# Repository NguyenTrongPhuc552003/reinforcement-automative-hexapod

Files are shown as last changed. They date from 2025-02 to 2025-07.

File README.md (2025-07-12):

## NOTE: This hexapod project is still under development and may not be fully functional. So, please wait for an official release is coming soon!

# Hexapod Robot Control System

A comprehensive control system for a six-legged robot (hexapod) using BeagleBone AI (or Black), featuring both kernel-space drivers and user-space applications with reinforcement learning capabilities.

<p align="center">
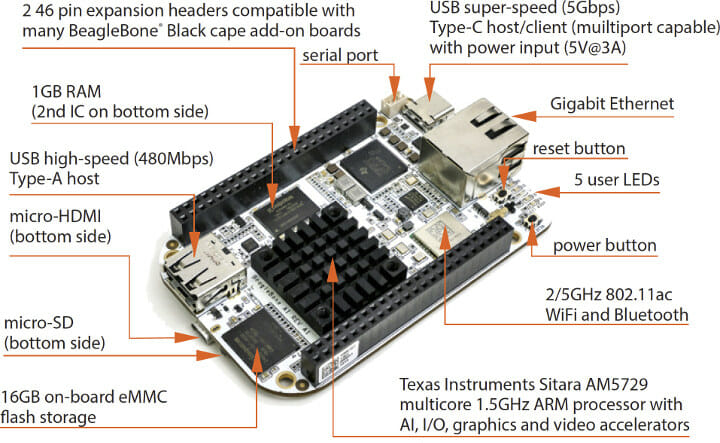
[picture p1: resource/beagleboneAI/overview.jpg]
Hexapod Robot
  
</p>

## Project Overview

This project implements a complete software stack for controlling a 6-legged robot with 18 servo motors (3 per leg), including:

- **Kernel-Space Components**:
  - Linux kernel driver for servo control (PCA9685 PWM controllers)
  - IMU sensor driver (MPU6050) for orientation sensing
  - Hardware abstraction layer for unified device access
  
- **User-Space Components**: 
  - Kinematics library for precise leg positioning
  - Gait generation for various walking patterns
  - Calibration system for mechanical offset compensation
  - Interactive control interface

- **Reinforcement Learning**:
  - TD3 (Twin Delayed Deep Deterministic Policy Gradient) implementation
  - Hardware acceleration via TIDL and OpenCL
  - Simulation-to-real transfer capabilities
  - On-robot inference engine

## System Architecture

The system follows a layered architecture with hardware abstraction. For visual reference, see the architecture diagrams in the `/docs/diagrams/image` directory:

- [Deployment Diagram](docs/diagrams/image/deployment.png): Hardware and software deployment
- [Component Diagram](docs/diagrams/image/component.png): Hardware component interactions
- [Sequence Diagram](docs/diagrams/image/sequence.png): Runtime interactions
- [State Diagram](docs/diagrams/image/state.png): Hardware state transitions
- [Class Diagram](docs/diagrams/image/class.png): Software class structure
- [Building Process](docs/diagrams/image/building.png): Build and deployment process

```t
.
├── driver/          # Linux kernel device drivers
├── app/             # User applications and libraries
├── docs/            # Documentation
└── scripts/         # Build and utility scripts
```

## Features

- Multiple gait patterns (tripod, wave, ripple)
- Real-time IMU feedback
- Inverse kinematics for precise leg control
- Hardware abstraction layer
- Comprehensive test suite
- Interactive debugging tools

## Prerequisites

- BeagleBone AI (or Black) running Linux 4.14+
- I2C enabled (bus 3)
- 18x servo motors (MG996R recommended)
- 1x MPU6050 IMU sensor
- 2x PCA9685 PWM controllers

## Quick Start

1. Build the kernel module:
   ```bash
   ./scripts/build.sh -b driver
   ```

2. Install the kernel module on BeagleBone AI:
   ```bash
   ./install.sh
   ```

3. Build user-space applications:
   ```bash
   ./scripts/build.sh -b app
   ```

4. Run the test utility on BeagleBone AI:
   ```bash
   ./test_servo
   ```

## Development

See individual README files in subdirectories for detailed development guides:
- [Kernel Driver README](driver/README.md)
- [User Space README](app/README.md)
- [Hardware Overview README](hardware/README.md)
- [Cross-compile Environment README](docker/README.md)
- [Documentation](docs/README.md)

## Testing

Individual tests:
```bash
./test_servo       # Test servo control
./test_mpu6050     # Test IMU sensor
./test_movement    # Test movements like tripod, ripple, ...
./test_calibration # Test servos offset for each leg
./test_hcsr04      # Test HC-SR04 sensor
```

## Troubleshooting

### Sensor Issues
- **Zero IMU readings**: The MPU6050 enters sleep mode to save power. The driver now automatically wakes it before readings.
- **Erratic IMU behavior**: Check I2C connections and ensure proper power supply voltage.

### Servo Issues
- **Servos not moving**: Check power supply and ensure driver is properly loaded
- **Erratic movement**: Verify calibration settings and check for loose connections

## Documentation

- [Hardware Setup](docs/hardware.md)
- [Software Architecture](docs/architecture.md)
- [Quick Start Guide](docs/quickstart.md)

## Contributing

1. Fork the repository
2. Create a feature branch
3. Commit your changes
4. Push to the branch
5. Create a Pull Request

## License


This project is licensed under the terms of the GNU General Public License v2.0.

## Authors

- StrongFood - I mean **"TrongPhuc"**

## Acknowledgments

- BeagleBoard.org
- Linux Kernel Community

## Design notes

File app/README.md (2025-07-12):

# Hexapod Robot Control Application

## Overview

This application provides a comprehensive control system for a 6-legged (hexapod) robot. It implements advanced kinematics, gait generation, sensor integration, and balance control to enable smooth and adaptive movement capabilities.

## Features

- **Multiple Gait Patterns**: Tripod, Wave, and Ripple gaits with configurable parameters
- **Adaptive Movement**: Dynamic speed, direction, and height control
- **Sensor Integration**: Support for MPU6050 (6-axis) and ADXL345 (3-axis) IMU sensors
- **Obstacle Detection**: Ultrasonic sensor integration with automatic avoidance
- **Balance Mode**: Self-stabilizing capability using IMU feedback
- **Interactive Control**: Real-time keyboard control interface
- **Diagnostics**: Performance monitoring and hardware verification tools
- **Calibration**: Joint calibration system for mechanical adjustments

## Architecture

The application follows a modular, object-oriented design with several key components:

- **Hexapod**: Hardware abstraction layer for the robot platform
- **Kinematics**: Mathematical model for leg positioning and inverse kinematics
- **Gait**: Movement pattern generation and coordination
- **Controller**: High-level control and command interpretation
- **Calibration**: Servo calibration management
- **Application**: Main program and user interface

## Building the Application

### Prerequisites

- ARM cross-compiler (arm-linux-gnueabihf-g++)
- C++17 compatible compiler
- Standard development libraries

### Compilation

The project uses a Makefile build system with the following targets:

```bash
# Standard build (optimized)
./scripts/build.sh -b app

# Debug build with additional debug information
./scripts/build.sh -b app DEBUG=1

# Run tests for help
./scripts/test.sh -h

# Clean build artifacts
./scripts/build.sh -c app

# Install to target location
./scripts/deploy.sh
```

## Usage

### Controls

| Key | Function |
|---|---|
| W / S | Move forward/backward |
| A / D | Rotate left/right |
| I / K | Raise/lower body |
| J / L | Tilt left/right |
| 1 - 3 | Select gait (1=Tripod, 2=Wave, 3=Ripple) |
| + / - | Increase/decrease speed |
| SPACE | Stop and center legs |
| B | Toggle balance mode |
| \[ / \] | Decrease/increase balance sensitivity |
| U | Toggle ultrasonic sensor |
| T | Toggle telemetry display |
| P | Toggle performance monitoring |
| M | Run servo diagnostics |
| H | Show help |
| Q | Quit |

### Telemetry Display

When enabled, the telemetry shows:
- IMU sensor readings
- Current controller state
- Performance metrics
- Balance mode status

### Balance Mode

The balance mode uses IMU sensor data to automatically adjust the robot's posture in response to tilting or uneven surfaces. This can be fine-tuned using the response factor and deadzone settings.

## Test Programs

The `test/` directory contains individual test programs for specific components:

- **servo.cpp**: Test servo motor control
- **mpu6050.cpp**: Test MPU6050 sensor readings
- **adxl345.cpp**: Test ADXL345 accelerometer readings
- **movement.cpp**: Test movement patterns
- **hcsr04.cpp**: Test ultrasonic distance sensor
- **calibration.cpp**: Test calibration procedures
- **balance.cpp**: Test balance mode functionality

## Safety Features

- Automatic obstacle detection and avoidance
- Graceful signal handling for clean shutdown
- Leg centering on startup and shutdown
- Configurable movement speed limits

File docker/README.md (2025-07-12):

# Docker Environment for Hexapod Robot

This directory contains Docker configuration for building and running the hexapod robot software in isolated containers. The Docker setup provides a consistent development and deployment environment across different systems.

## Available Containers

### 1. Driver Container (`driver.Dockerfile`)

The driver container provides the low-level hardware interface for the hexapod robot:

- PCA9685 servo driver interface
- IMU sensors (MPU6050, ADXL345)
- GPIO control for ultrasonic sensors
- I2C bus management

### 2. Application Container (`app.Dockerfile`)

The application container runs the high-level control software:

- Kinematics and movement algorithms
- Reinforcement learning models (TD3)
- Gait generation and control
- User interface and command processing

### 3. Python TD3 Container (`pytd3.Dockerfile`)

The Python TD3 container runs the TD3 reinforcement learning algorithm:

- TD3 algorithm implementation
- Training and evaluation scripts
- Integration with the application container

## Building the Containers

### Using Docker Compose (Recommended)

The easiest way to build all available containers is using Docker Compose:

```bash
# From the project root directory
./scripts/build.sh -i
```

### Building Individual Containers

To build containers individually:

```bash
# Build the driver container
./scripts/build.sh -i driver

# Build the application container
./scripts/build.sh -i app

# Build the Python TD3 container
./scripts/build.sh -i pytd3
```

## Running the Containers

### Using Docker Compose (Recommended)

```bash
# Start all containers
docker-compose up

# Run in detached mode
docker-compose up -d

# Stop the containers
docker-compose down
```

### Running Individual Containers

```bash
# Run the driver container with hardware access
docker run --privileged --device=/dev/i2c-1 -v /dev:/dev \
  --name hexapod-driver hexapod-driver

# Run the application container
docker run --network=host --name hexapod-app hexapod-app
```

## Configuration

### Environment Variables

You can configure the containers using environment variables:

- `HEXAPOD_LOG_LEVEL`: Set logging level (DEBUG, INFO, WARNING, ERROR)
- `HEXAPOD_HARDWARE_ENABLED`: Enable/disable hardware interface (true/false)
- `HEXAPOD_SENSOR_TYPE`: Set the sensor type (AUTO, MPU6050, ADXL345)

Example using Docker Compose:

```yaml
services:
  app:
    environment:
      - HEXAPOD_LOG_LEVEL=DEBUG
      - HEXAPOD_SENSOR_TYPE=MPU6050
```

### Volume Mounts

The Docker Compose configuration includes several useful volume mounts:

- `/dev`: Provides access to hardware devices
- `/var/log/hexapod`: Stores log files
- `/data/models`: Persists trained models

## Development Workflow

For development, you can mount your source code as volumes:

```bash
docker run -v $(pwd)/app:/app -v $(pwd)/driver:/driver \
  --privileged --device=/dev/i2c-1 \
  hexapod-driver
```

## Troubleshooting

### Hardware Access Issues

If the container can't access hardware devices:

1. Make sure you're using the `--privileged` flag
2. Verify that device paths are correctly mounted
3. Check that the user in the container has permission to access the devices

### Container Communication Issues

If containers can't communicate:

1. Check that they're on the same network
2. Verify that required ports are exposed
3. Ensure service names resolve correctly in Docker Compose

## Security Considerations

The containers use the `--privileged` flag to access hardware, which grants extensive permissions. For production deployments, consider using more restrictive permissions with specific device mappings.

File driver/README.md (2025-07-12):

# Hexapod Robot Driver

## Overview

This directory contains the kernel-level driver for the hexapod robot platform. The driver provides a hardware abstraction layer that interfaces with the servo controllers, IMU sensors, and other hardware components, exposing them through a unified device interface to user applications.

## Features

- **Servo Motor Control**: Precise control of 18 servo motors through the PCA9685 PWM controller
- **Dual IMU Support**:
  - MPU6050 (6-axis: accelerometer + gyroscope)
  - ADXL345 (3-axis accelerometer)
  - Auto-detection capability
- **Joint Calibration**: Hardware-level servo calibration to compensate for mechanical variations
- **Safe Mode Operation**: Automatic protection against invalid positions and commands

## Hardware Components

The driver interfaces with the following hardware components:

| Component | Description | Interface | Address (configurable) |
|---|---|---|---|
| PCA9685_1 | 16-channel PWM controller | I2C | 0x40 |
| PCA9685_2 | 16-channel PWM controller | I2C | 0x41 |
| MPU6050 | 6-axis IMU sensor | I2C | 0x68 |
| ADXL345 | 3-axis accelerometer | I2C | 0x53 |

## Directory Structure

```t
driver/
├── inc/
│   ├── mpu6050.h          # MPU6050 IMU sensor data structures
│   └── pca9685.h          # PCA9685 PWM controller data structures
│   └── adxl345.h          # ADXL345 accelerometer data structures
│   └── servo.h            # Servo motor data structures
├── src/
│   ├── mpu6050.c          # MPU6050 IMU sensor handling code
│   ├── pca9685.c          # PCA9685 PWM controller handling code
│   ├── adxl345.c          # ADXL345 accelerometer handling code
│   └── servo.c            # Servo motor handling code
│   └── main.c             # Main application code
├── Makefile               # System build instructions
└── README.md              # This file
```

## Building and Installation

### Prerequisites

- Linux kernel headers
- Cross-compilation toolchain
- BeagleBone AI device tree (unused yet)

### Build Commands

```bash
./scripts/build.sh -b driver
```

### Installation Steps

1. Copy module:
   ```bash
   ./scripts/deploy.sh
   ```

2. Load module:
   ```bash
   ./scripts/deploy.sh -i
   ```

3. Verify:
   ```bash
   dmesg | grep hexapod
   ls -l /dev/hexapod
   ```

## Driver Interface

### IOCTL Commands

- `SET_LEG_POSITION`: Set servo angles for a specific leg
- `GET_IMU_DATA`: Read IMU data (accelerometer and gyroscope)
- `CALIBRATE`: Set servo calibration offsets
- `CENTER_ALL`: Center all servos to neutral position

### Data Structures

- `hexapod_leg_joint`: Contains hip, knee, ankle angles
- `hexapod_leg_cmd`: Contains leg number and joint angles
- `hexapod_calibration`: Contains leg number and joint offsets
- `hexapod_imu_data`: Contains accelerometer and gyroscope data

### Device Node

- Path: `/dev/hexapod`
- Permissions: 666
- Mode: Character device

## Debugging

Enable debug messages:

```bash
echo 1 > /sys/module/hexapod_driver/parameters/debug
```

## Development

### Adding Features

1. Define IOCTL command in `src/main.c`
2. Implement handler in `src/main.c`
3. Add to user documentation

### Testing

```bash
# Load with debug
./install.sh debug=1

# Monitor messages
dmesg -w
```

### Error Handling

- I2C communication errors
- Invalid parameters
- Resource cleanup
- User input validation

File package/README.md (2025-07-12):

# Hexapod Robot Control System

A comprehensive control system for hexapod robots featuring kernel-level hardware drivers, user space applications, and reinforcement learning capabilities.

## Package Contents

This installation package includes:

### Kernel Driver (`/lib/modules/*/extra/`)
- **hexapod_driver.ko**: Low-level hardware interface kernel module
- Provides device file interface at `/dev/hexapod`
- Supports PCA9685 PWM controller and IMU sensors

### Applications (`/usr/local/bin/`)  
- **hexapod_app**: Main interactive control application
- **test_***: Hardware testing and diagnostic utilities
- Complete keyboard-controlled interface for robot operation

### Utilities (`/opt/hexapod/`)
- **install.sh**: Kernel module management
- **monitor.sh**: System monitoring and diagnostics
- Configuration and calibration tools

## Quick Start

1. **Verify Installation**
   ```bash
   lsmod | grep hexapod_driver
   ls -l /dev/hexapod
   ```

2. **Run Main Application**
   ```bash
   ./hexapod_app
   ```

3. **Test Hardware Components**
   ```bash
   ./test_mpu6050    # Test IMU sensor
   ./test_servo      # Test servo motors
   ./test_balance    # Test balance system
   ```

## Hardware Requirements

- BeagleBone AI or compatible ARM platform
- PCA9685 16-channel PWM driver
- MPU6050 or ADXL345 IMU sensor
- 18 servo motors (3 per leg × 6 legs)
- HC-SR04 ultrasonic sensor (optional)

## System Requirements

- Linux kernel 4.14+ with I2C support
- ARM architecture (armhf/arm64)
- Root access for hardware control
- I2C interface enabled in device tree

## Documentation

Detailed documentation available in:
- `/usr/local/bin/README.md` - Application usage
- `/opt/hexapod/README.md` - Utility scripts  
- `/lib/modules/*/extra/README.md` - Kernel module

## Troubleshooting

**Module Loading Issues:**
```bash
sudo dmesg | grep hexapod
sudo modprobe hexapod_driver
```

**Permission Errors:**
```bash
sudo chmod 666 /dev/hexapod
sudo usermod -a -G dialout $USER
```

**Hardware Detection:**
```bash
i2cdetect -y -r 3
./monitor.sh -h   # Call for help more options
```

## Updates and Support

- Project repository: https://github.com/NguyenTrongPhuc552003/reinforcement-automative-hexapod.git
- Issue tracker: https://github.com/NguyenTrongPhuc552003/reinforcement-automative-hexapod/issues
- Documentation: https://github.com/NguyenTrongPhuc552003/reinforcement-automative-hexapod/tree/main/docs

## Version Information

Check installed version:
```bash
dpkg -l | grep hexapod
modinfo hexapod_driver | grep version
```

---
© 2025 StrongFood. Licensed under GPL v2.0

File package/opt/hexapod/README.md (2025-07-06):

# Hexapod Utilities

This directory contains utility scripts for the Hexapod Robot Control System.

## Available Scripts

### install.sh
Kernel module management utility
```bash
# Install/load kernel module
sudo ./install.sh

# Remove/unload kernel module  
sudo ./install.sh -r

# Show status
./install.sh -s
```

### monitor.sh  
System monitoring and diagnostic tool
```bash
# Monitor system activities
./monitor.sh

# Monitor with logging
./monitor.sh -l

# Continuous monitoring
./monitor.sh -c
```

## Additional Utilities
If PyTD3 reinforcement learning module is installed:
- **pytd3/**: Python reinforcement learning components
- **config/**: Configuration files and calibration data

## System Integration
These utilities are designed to work with:
- BeagleBone AI hardware platform
- Debian-based Linux distributions  
- I2C hardware interface
- GPIO control systems

## Maintenance
Regular maintenance tasks:
```bash
# Check system health
sudo ./monitor.sh -h

# Backup calibration data
cp /etc/hexapod/calibration.cfg ~/hexapod_backup.cfg

# Update kernel module
sudo ./install.sh -r && sudo ./install.sh
```

## Support
For technical support:
- Check system logs: `journalctl -u hexapod`
- Review hardware connections
- Verify I2C functionality: `i2cdetect -r 1`

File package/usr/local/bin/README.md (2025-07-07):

# Hexapod Executables

This directory contains the main applications and test programs for the Hexapod Robot Control System.

## Main Application
- **hexapod_app**: Main hexapod control application with keyboard interface

## Test Programs
- **test_mpu6050**: Test MPU6050 6-axis IMU sensor functionality
- **test_adxl345**: Test ADXL345 3-axis accelerometer  
- **test_servo**: Test individual servo motor control
- **test_movement**: Test basic movement patterns and gaits
- **test_balance**: Test balance control system with IMU feedback
- **test_calibration**: Interactive servo calibration utility
- **test_hcsr04**: Test HC-SR04 ultrasonic distance sensor

## Usage
All programs require root privileges to access hardware:

```bash
# Run main application
sudo hexapod_app

# Test specific hardware
sudo test_mpu6050
sudo test_servo
sudo test_balance

# Interactive calibration
sudo test_calibration
```

## Main Application Controls
- **WASD**: Movement (forward/back/rotate)
- **IJKL**: Height and tilt control  
- **123**: Gait selection (tripod/wave/ripple)
- **+/-**: Speed adjustment
- **Space**: Stop and center
- **Q**: Quit

## Prerequisites
- Kernel module must be loaded (hexapod_driver)
- Hardware must be properly connected
- I2C interface must be enabled

## Troubleshooting
- Check kernel module: `lsmod | grep hexapod_driver`
- Verify device file: `ls -l /dev/hexapod`
- Monitor system logs: `dmesg | tail`

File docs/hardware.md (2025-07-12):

# Hexapod Hardware Documentation

## Overview

This document describes the hardware components of the hexapod robot and provides detailed specifications, wiring diagrams, and configuration information.

Hexapod Hardware Overview

For detailed visual representation of hardware organization, see the [Component Diagram](diagrams/image/component.png) and [Deployment Diagram](diagrams/image/deployment.png).

## Robot Specifications

| Parameter | Value |
|---|---|
| Dimensions | 300mm × 300mm × 150mm (L×W×H) |
| Weight | ~1.5kg (without battery) |
| Operating Voltage | 6V (servos), 5V (logic) |
| Power Consumption | 2-10A depending on movement |
| Maximum Speed | ~0.3m/s |
| Control Board | BeagleBone AI/Black |
| Servo Motors | 18× MG996R (or compatible) |
| Degrees of Freedom | 18 (3 per leg) |
| Operating Time | ~1 hour (with 2800mAh battery) |
| Sensing | 6-axis IMU (accelerometer + gyroscope) |

## Component List

| Component Description | Quantity | Notes |
|---|---|---|
| BeagleBone AI/Black | 1 | Main control board |
| MG996R Servo Motors | 18 | 3 per leg (hip, knee, ankle) |
| PCA9685 PWM Controller | 2 | 16-channel PWM controller |
| MPU6050 IMU Sensor | 1 | 6-axis accelerometer + gyroscope |
| 6V 10A Power Supply | 1 | For powering servos |
| Voltage Regulator 5V | 1 | For logic power |
| Aluminum/Plastic Brackets | 18 | For leg joints |
| Body Frame | 1 | Central chassis |
| Leg Segments | 18 | Connecting rods for legs |
| Foot Pads | 6 | Non-slip contact points |
| Wires and Connectors | Assorted | For electrical connections |
| Mounting Hardware | Assorted | Screws, nuts, standoffs |

## Mechanical Architecture

The hexapod follows a standard hexapod design with 6 legs arranged radially around a central body:

- **Body**: Hexagonal or circular platform housing the control electronics
- **Legs**: 6 legs with 3 joints each (hip, knee, ankle)
- **Joint Arrangement**:
  - Hip: Rotates horizontally (parallel to body)
  - Knee: Rotates vertically (perpendicular to hip)
  - Ankle: Rotates vertically (perpendicular to knee)

### Dimensions

- **Body Diameter**: 150mm
- **Leg Segments**:
  - Hip to Knee (COXA): 30mm
  - Knee to Ankle (FEMUR): 85mm
  - Ankle to Foot (TIBIA): 130mm
- **Total Leg Extension**: ~245mm fully extended

## Electrical Architecture

### Power System

- **Main Power**: 6V, 10A power supply or battery
- **Power Distribution**:
  - Separate power rails for servos and logic
  - Common ground between all components
- **Protection**:
  - Fuse on main power line (10A)
  - Reverse polarity protection
  - Logic level isolation between BeagleBone and servo power

### Control System

- **Main Controller**: BeagleBone AI/Black
  - AM5729 processor
  - 1GB DDR3 RAM
  - 16GB onboard eMMC
  - Linux operating system

- **Servo Control**: Via PCA9685 PWM controllers
  - 2× PCA9685 boards (primary and secondary)
  - I2C communication from BeagleBone
  - 50Hz PWM signal generation

- **Sensing**:
  - MPU6050 IMU for orientation detection
  - Additional sensor connections available for expansion

## I2C Bus Configuration

The I2C bus 2 on BeagleBone is used for connecting sensors and actuators:

| Device Description | I2C Address | Bus | Description |
|--- |---|-----|---|
| MPU6050 | 0x68 | 3 | 6-axis IMU sensor |
| PCA9685 Primary | 0x40 | 3 | 16-channel PWM controller |
| PCA9685 Secondary  | 0x71 | 3 | 16-channel PWM controller |

### BeagleBone Pin Configuration

| BeagleBone Pin | Function | Connected To |
|---|---|---|
| P9_19 | I2C2_SCL | SCL of all I2C devices |
| P9_20 | I2C2_SDA | SDA of all I2C devices |
| P9_1, P9_2 | GND | Ground for all devices |
| P9_7, P9_8 | SYS_5V | Logic power for shields |
| P9_3, P9_4 | DC_3.3V | 3.3V sensors (e.g. MPU6050) |

## Servo Motor Specifications

Type: MG996R (or compatible) high-torque metal gear servo

| Parameter | Specification |
|---|---|
| Operating Voltage  | 4.8V to 6.6V |
| Stall Torque | 9.4 kg·cm (4.8V) / 11 kg·cm (6.0V) |
| Speed | 0.17 sec/60° (4.8V) / 0.14 sec/60° (6.0V) |
| Weight | 55g |
| Dimensions | 40.7 × 19.7 × 42.9 mm |
| Control Signal | PWM, 1-2ms pulse, 50Hz |
| Rotation Range | 180° (controlled as ±90°) |
| Working Temperature| -30°C to +60°C |

## Servo Mapping

Each servo is connected to a specific channel on the PCA9685 controllers.

| Leg | Joint | PWM Channel  | Controller |
|-----|---|---|---|
| 0 | Hip | 0 | Primary |
| | Knee  | 1 | Primary |
|_____| Ankle | 2 | Primary |
| 1 | Hip | 4 | Primary |
| | Knee  | 5 | Primary |
|_____| Ankle | 6 | Primary |
| 2 | Hip | 8 | Primary |
| | Knee  | 9 | Primary |
|_____| Ankle | 10 | Primary |
| 3 | Hip | 0 | Secondary  |
| | Knee  | 1 | Secondary  |
|_____| Ankle | 2 | Secondary  |
| 4 | Hip | 4 | Secondary  |
| | Knee  | 5 | Secondary  |
|_____| Ankle | 6 | Secondary  |
| 5 | Hip | 8 | Secondary  |
| | Knee  | 9 | Secondary  |
|_____| Ankle | 10 | Secondary  |

## MPU6050 IMU Configuration

The MPU6050 provides orientation data for the hexapod:

| Parameter | Configuration |
|---|---|
| I2C Address | 0x68 |
| Accelerometer Range | ±2g |
| Gyroscope Range | ±500 degrees/second |
| Sample Rate | 100Hz |
| Low-Pass Filter | 10Hz |
| Orientation | X forward, Y right, Z up |

### Power Management

The MPU6050 has built-in power management features that may put it into sleep mode after periods of inactivity. The driver automatically handles waking the device when readings are requested, ensuring consistent sensor data even after extended periods between readings.

Key power management features:
- Sleep mode: Automatically entered to conserve power
- Wake-on-read: Driver automatically detects and wakes the device when readings are requested
- Clock source: PLL with X-axis gyroscope reference for stability

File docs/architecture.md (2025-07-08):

# Hexapod Robot System Architecture

This document describes the architecture of the reinforcement learning-enabled hexapod robot system, detailing the major components, their interactions, and the key design patterns used.

## System Overview

The hexapod robot system is a multi-layered architecture that combines hardware control, kinematics, gait generation, and high-level control with reinforcement learning capabilities. The system is designed to be modular, extensible, and robust to environmental changes.

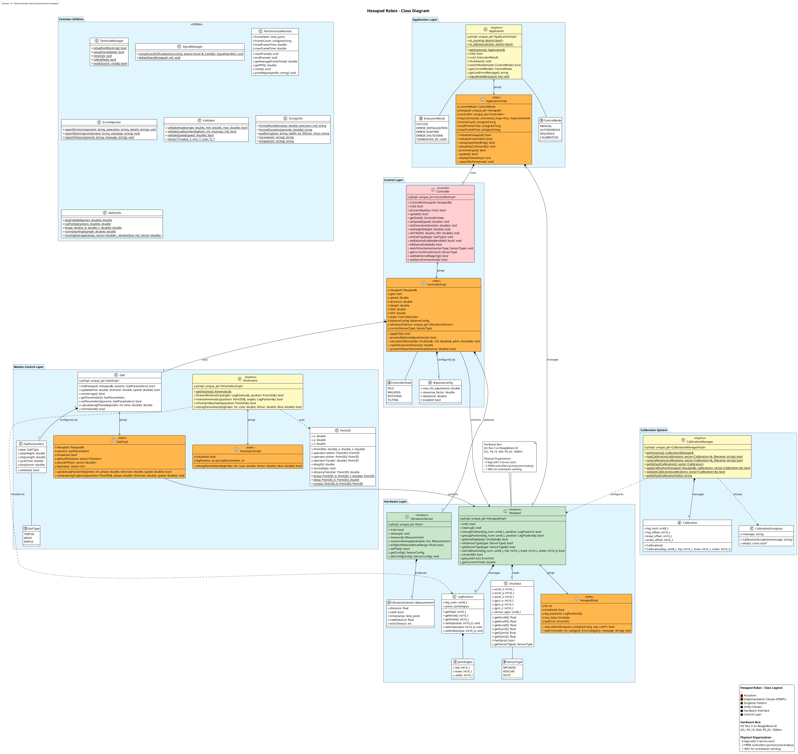
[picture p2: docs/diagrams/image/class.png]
Architecture Overview


## Architectural Layers

The system is organized into the following layers, from lowest to highest level:

### 1. Hardware Layer

The hardware layer provides direct interaction with the physical components of the robot:

- **Kernel Driver**: Low-level kernel module for hardware access
- **Hardware Abstraction**: C++ interface to the kernel driver
- **Sensor Integration**: IMU and ultrasonic sensor management

#### Key Components:
- `hexapod::Hexapod`: Hardware abstraction layer for servo control
- `PCA9685` driver: PWM controller for servo motors
- `MPU6050` and `ADXL345` drivers: IMU sensor interfaces
- `UltrasonicSensor`: HC-SR04 distance sensor interface

### 2. Kinematics Layer

The kinematics layer handles the mathematical models for leg positioning:

- **Forward Kinematics**: Calculate leg positions from joint angles
- **Inverse Kinematics**: Calculate joint angles from desired positions
- **3D Geometry**: Vector operations and transformations

#### Key Components:
- `kinematics::Kinematics`: Singleton class providing forward and inverse kinematics
- `kinematics::Point3D`: 3D vector class with mathematical operations

### 3. Gait Layer

The gait layer manages leg movement patterns and coordination:

- **Gait Patterns**: Tripod, wave, and ripple gaits
- **Trajectory Generation**: Calculate foot paths for smooth movement
- **Gait Parameters**: Configurable stepping height, length, and timing

#### Key Components:
- `gait::Gait`: Gait pattern generator
- `gait::GaitParameters`: Configuration for different gait types

### 4. Control Layer

The control layer provides high-level robot control:

- **Movement Control**: Direction and speed management
- **Balance System**: Active balance using IMU feedback
- **Obstacle Avoidance**: Distance-based movement adjustment

#### Key Components:
- `controller::Controller`: High-level robot controller
- `controller::BalanceConfig`: Balance system parameters

### 5. Application Layer

The application layer handles user interaction and system coordination:

- **User Interface**: Keyboard input and telemetry display
- **System Management**: Initialization, shutdown, and error handling
- **Performance Monitoring**: Timing and metrics tracking

#### Key Components:
- `application::Application`: Main application singleton
- `common::TerminalManager`: Terminal input handling
- `common::SignalManager`: Signal handling for graceful shutdown
- `calibration::CalibrationManager`: Servo calibration management

### 6. Reinforcement Learning Layer

The reinforcement learning layer provides adaptive behavior:

- **TD3 Algorithm**: Twin Delayed Deep Deterministic Policy Gradient
- **State Representation**: Robot state encoding
- **Action Mapping**: Transform RL outputs to robot commands

#### Key Components:
- `pytd3` module: Python implementation of TD3 algorithm
- `td3bridge`: C++/Python communication interface

## Communication and Data Flow

### Internal Communication

Components communicate through well-defined interfaces:

1. **Hardware to Kinematics**: The kinematics layer translates between joint angles and 3D positions
2. **Kinematics to Gait**: The gait layer uses kinematics to generate coordinated leg movements
3. **Gait to Controller**: The controller uses the gait generator to produce walking patterns
4. **Controller to Application**: The application orchestrates the controller based on user input

### External Communication

The system communicates with external components through:

- **Kernel Interface**: IOCTL calls for hardware communication
- **Python Bridge**: ZeroMQ-based interface for reinforcement learning integration
- **Telemetry Output**: Real-time system status display

## Key Design Patterns

### 1. PIMPL (Pointer to Implementation)

The system extensively uses the PIMPL idiom to:
- Hide implementation details
- Maintain ABI stability
- Reduce compilation dependencies

Example implementation:
```cpp
// Header file
class Controller {
public:
    Controller(hexapod::Hexapod &hexapod);
    ~Controller();
    bool init();
    // Public API methods
private:
    std::unique_ptr<ControllerImpl> pImpl;
};

// Implementation file
class ControllerImpl {
public:
    ControllerImpl(hexapod::Hexapod &hexapod) : hexapod(hexapod) {}
    // Implementation details
    hexapod::Hexapod &hexapod;
};

Controller::Controller(hexapod::Hexapod &hexapod)
    : pImpl(std::make_unique<ControllerImpl>(hexapod)) {}
```

### 2. Singleton Pattern

Singletons are used for system-wide resources:
- `Application`: Main application controller
- `Kinematics`: Shared kinematics calculations
- `CalibrationManager`: Centralized calibration management

Example implementation:
```cpp
class Kinematics {
public:
    static Kinematics& getInstance() {
        static Kinematics instance;
        return instance;
    }
    
    // Delete copy and move operations
    Kinematics(const Kinematics&) = delete;
    Kinematics& operator=(const Kinematics&) = delete;
    Kinematics(Kinematics&&) = delete;
    Kinematics& operator=(Kinematics&&) = delete;

private:
    Kinematics() {}
};
```

### 3. Strategy Pattern

The system uses the strategy pattern for different gait types and control modes:
- Different gaits (tripod, wave, ripple) share a common interface
- Control modes (manual, autonomous) can be switched at runtime

### 4. Observer Pattern

The system implements observer patterns for monitoring:
- Signal handlers observe system signals
- Performance monitors observe system metrics

### 5. Factory Pattern

Factory patterns are used for creating specialized objects:
- Gait pattern creation
- Calibration data initialization

## Error Handling Strategy

The system implements a comprehensive error handling approach:

1. **Error Classification**: Errors are categorized by type (hardware, communication, etc.)
2. **Error Propagation**: Errors propagate upward with additional context
3. **Retry Logic**: Critical operations have built-in retry mechanisms
4. **Graceful Degradation**: The system continues operating with reduced functionality when possible

Example error handling:
```cpp
bool Hexapod::setLegPosition(uint8_t leg_num, const LegPosition &position)
{
    if (!pImpl->initialized) {
        pImpl->setError(ErrorInfo::ErrorCode::NOT_INITIALIZED, ErrorCategory::PARAMETER,
                       "Hexapod not initialized");
        return false;
    }
    
    // Implement retry logic for hardware operations
    for (int retry = 0; retry < MAX_RETRIES; retry++) {
        if (sendPositionCommand(leg_num, position))
            return true;
            
        if (retry < MAX_RETRIES - 1)
            usleep(RETRY_DELAY_US);
    }
    
    pImpl->setError(ErrorInfo::ErrorCode::COMM_ERROR, ErrorCategory::COMMUNICATION,
                   "Failed to set leg position after retries");
    return false;
}
```

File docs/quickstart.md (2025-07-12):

# Hexapod Robot - Quick Start Guide

This guide will help you quickly set up and operate the reinforcement learning-enabled hexapod robot.

## Prerequisites

- BeagleBone Black or compatible single-board computer
- Properly assembled hexapod with 18 servos (3 per leg)
- IMU sensor (MPU6050 or ADXL345)
- Optional: Ultrasonic distance sensor
- Power supply (7.4V-12V recommended)

## Installation

### Option 1: Using Pre-built Image

1. Download the pre-built image from our repository
2. Flash the image to a microSD card
3. Insert the card into your BeagleBone and power on
4. The system will boot automatically

### Option 2: Manual Installation

1. Install dependencies:
   ```bash
   sudo apt update
   sudo apt install -y build-essential cmake git docker
   ```

2. Clone the repository:
   ```bash
   git clone https://github.com/NguyenTrongPhuc552003/reinforcement-automative-hexapod.git
   cd reinforcement-automative-hexapod
   ```

3. Build the project:
   ```bash
   ./scripts/build.sh
   ```

4. Deploy the applications to your BeagleBone:
   ```bash
   ./scripts/deploy.sh
   ```

## Hardware Setup

1. Connect the servo controller (PCA9685) to I2C bus
2. Connect the IMU sensor (MPU6050 or ADXL345) to I2C bus
3. Connect ultrasonic sensor (optional) to designated GPIO pins
4. Connect power supply to the servo power rail

## Running the Hexapod

1. Install the hexapod driver:
   ```bash
   ./install.sh
   ```

2. Launch the hexapod application:
   ```bash
   ./hexapod_app
   ```

3. Test the hexapod's movement:
   ```bash
   ./test_movement
   ```

## Basic Controls

Once the application is running, use the following keyboard controls:

| Key | Function |
|---|---|
| W | Walk forward |
| S | Walk backward |
| A | Rotate left |
| D | Rotate right |
| I / K | Raise/lower body |
| J / L | Tilt left/right |
| 1 / 2 / 3 | Switch gait (Tripod/Wave/Ripple) |
| +/- | Increase/decrease speed |
| Space | Stop and center legs |
| B | Toggle balance mode |
| \[ / \] | Adjust balance sensitivity |
| U | Toggle ultrasonic sensor |
| T | Toggle telemetry display |
| P | Toggle performance monitoring |
| H | Display help |
| Q | Quit application |

## Advanced Features

### Balance Mode

Enable automatic balancing with the 'B' key. The hexapod will use IMU data to maintain stability:
- Use '\[' and '\]' to adjust sensitivity
- Balance works in all movement modes

### Sensor Options

The system supports multiple sensor configurations:
- MPU6050: 6-axis IMU with accelerometer and gyroscope
- ADXL345: 3-axis accelerometer
- Switch between them with 'X' and 'C' keys

### Obstacle Avoidance

When ultrasonic sensor is enabled ('U' key):
- Automatically slows down when approaching obstacles
- Stops and backs away from close obstacles

## Troubleshooting

### Common Issues

1. **Servo jittering**
   - Check power supply voltage
   - Verify calibration values
   - Ensure I2C connection is stable

2. **Unresponsive controls**
   - Check if terminal is in the correct mode
   - Verify driver is loaded (`lsmod | grep hexapod`)
   - Restart the application

3. **IMU errors**
   - Verify I2C connections
   - Try switching sensor type (MPU6050/ADXL345)
   - Run diagnostics with 'P' command

### Running Diagnostics

Use the 'M' key to run comprehensive diagnostics on:
- Servo mapping
- Controller connectivity
- Sensor readings

## Next Steps

After getting familiar with basic operation:

1. Explore the reinforcement learning module in `pytd3/`
2. Customize gait patterns in the `gait.cpp` file in `app/src/`
3. Create your own sequences and behaviors
4. See the full documentation for advanced API usage

## Support

For additional help, please:
- Check the complete documentation in the `docs/` directory
- File issues on our GitHub repository
- Join our community Discord server for real-time assistance

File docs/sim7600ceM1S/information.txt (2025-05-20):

•	Supply voltage range on VCC PIN: 4.8V ~ 16V
•	Control Via AT Commands
•	Operation temperature: -40℃ to +85℃
•	Dimensions: 30.0*30.0*2.9mm
•	Weight: : 5.7 ± 0.2g
•	GNSS:GPS/GLONASS/BeiDou/Galileo
•	Frequency:
•	LTE-FDD B1/B3/B5/B8
•	UMTS/HSDPA/HSPA+ B1/B8
•	GSM/GPRS/EDGE 900/1800MHz

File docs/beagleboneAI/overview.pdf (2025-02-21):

# BeagleBone AI

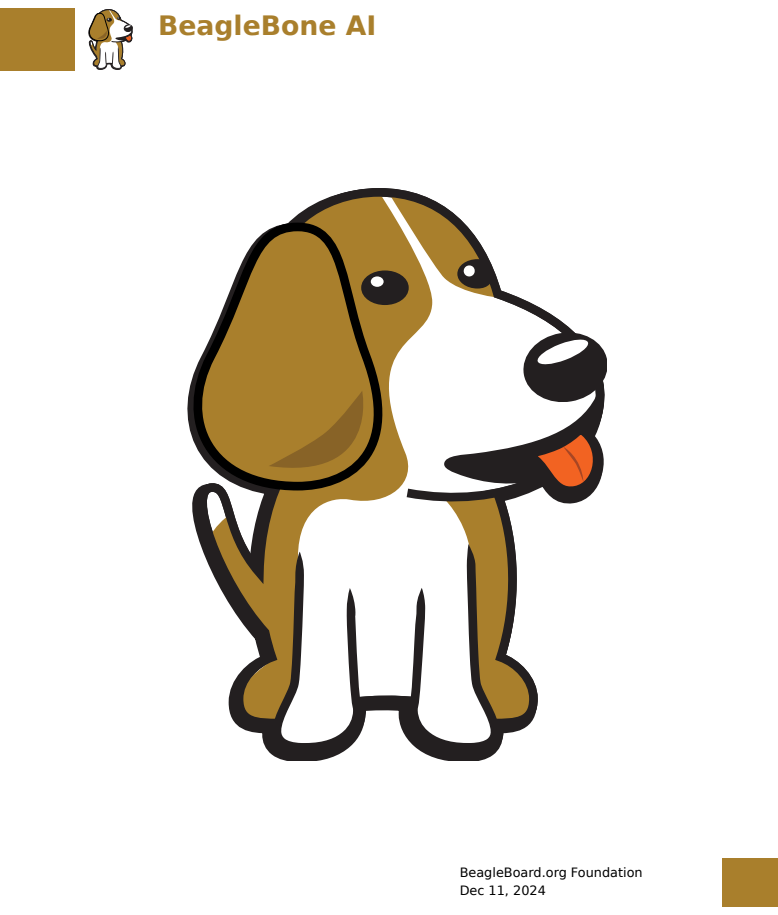
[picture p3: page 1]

BeagleBoard.org Foundation
Dec 11, 2024

# Table of contents

1 Introduction | 3
2 Quick start | 7
3 Design and specifications | 17

i

4 Expansion | 39
5 Cape Board Support | 57
6 Demos & Tutorials | 61
7 Additional Support Information | 69

ii

BeagleBone AI

BeagleBone AI is based on the Texas Instruments AM5729 (https://www.ti.com/product/AM5729) dual-core Cortex-A15 SoC with flexible BeagleBone Black header and mechanical compatibility. BeagleBone AI makes it easy to explore how artificial intelligence (AI) can be used in everyday life via the TI C66x digital-signal-processor (DSP) cores and embedded-vision-engine (EVE) cores supported through an optimized TIDL machine learning OpenCL API with pre-installed tools. Focused on everyday automation in industrial, commercial and home applications.

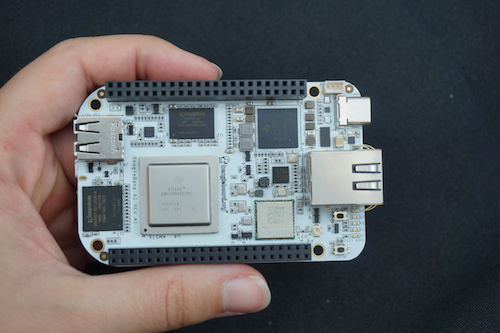
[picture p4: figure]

Table of contents | 1

### 2 Table of contents

# Chapter 1

# Introduction

Built on the proven BeagleBoard.org® open source Linux approach, BeagleBone® AI fills the gap between small SBCs and more powerful industrial computers. Based on the Texas Instruments AM5729, developers have access to the powerful SoC with the ease of BeagleBone® Black header and mechanical compatibility. BeagleBone® AI makes it easy to explore how artificial intelligence (AI) can be used in everyday life via TI C66x digital-signal-processor (DSP) cores and embedded-vision-engine (EVE) cores supported through an optimized TIDL machine learning OpenCL API with pre-installed tools. Focused on everyday automation in industrial, commercial and home applications.

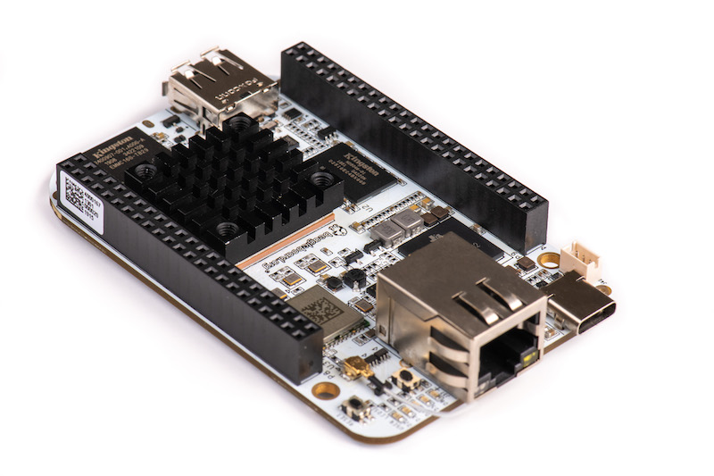
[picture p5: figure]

3

## 1.1 BeagleBone AI Overview

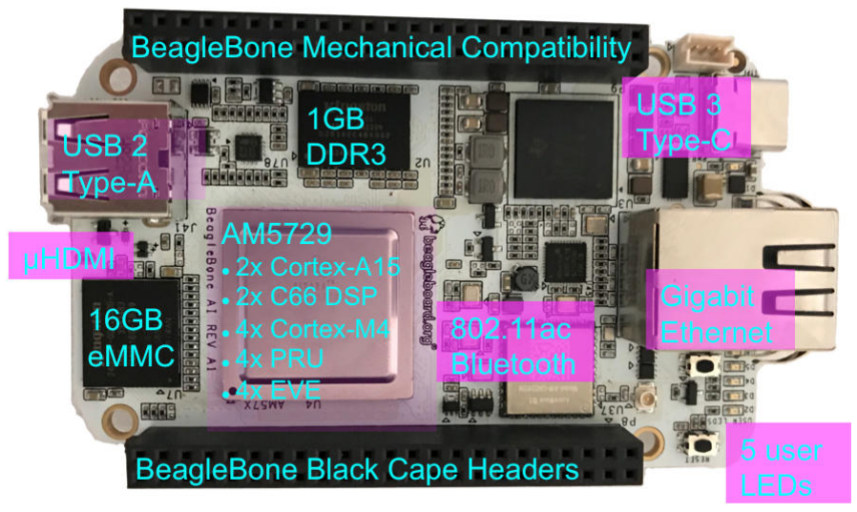
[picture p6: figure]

### 1.1.1 BeagleBone® AI Features

## 1.2 Main Processor Features of the AM5729 Within BeagleBone® AI

- Dual 1.5GHz ARM® Cortex®-A15 with out-of-order speculative issue 3-way superscalar execution pipeline for the fastest execution of existing 32-bit code
- 2 C66x Floating-Point VLIW DSP supported by OpenCL
- 4 Embedded Vision Engines (EVEs) supported by TIDL machine learning library
- 2x Dual-Core Programmable Real-Time Unit (PRU) subsystems (4 PRUs total) for ultra low-latency control and software generated peripherals
- 2x Dual ARM® Cortex®-M4 co-processors for real-time control
- IVA-HD subsystem with support for 4K @ 15fps H.264 encode/decode and other codecs @ 1080p60
- Vivante® GC320 2D graphics accelerator
- Dual-Core PowerVR® SGX544™ 3D GPU

## 1.3 Communications

- BeagleBone Black header and mechanical compatibility
- 16-bit LCD interfaces
- 4+ UARTs
- 2 I2C ports
- 2 SPI ports

### 4 Chapter 1. Introduction

- Lots of PRU I/O pins

## 1.4 Memory

- 1GB DDR3L
- 16GB on-board eMMC flash

## 1.5 Connectors

- USB Type-C connector for power and SuperSpeed dual-role controller
- Gigabit Ethernet
- 802.11ac 2.4/5GHz WiFi via the AzureWave AW-CM256SM

## 1.6 Out of Box Software

- Zero-download out of box software environment

### 1.6.1 Board Component Locations

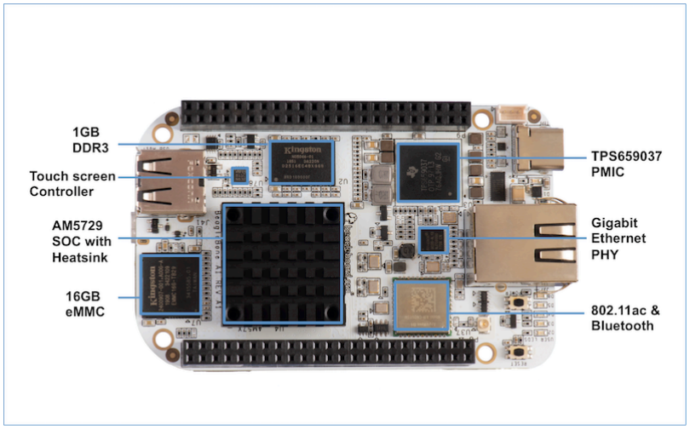
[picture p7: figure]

1.4. Memory | 5

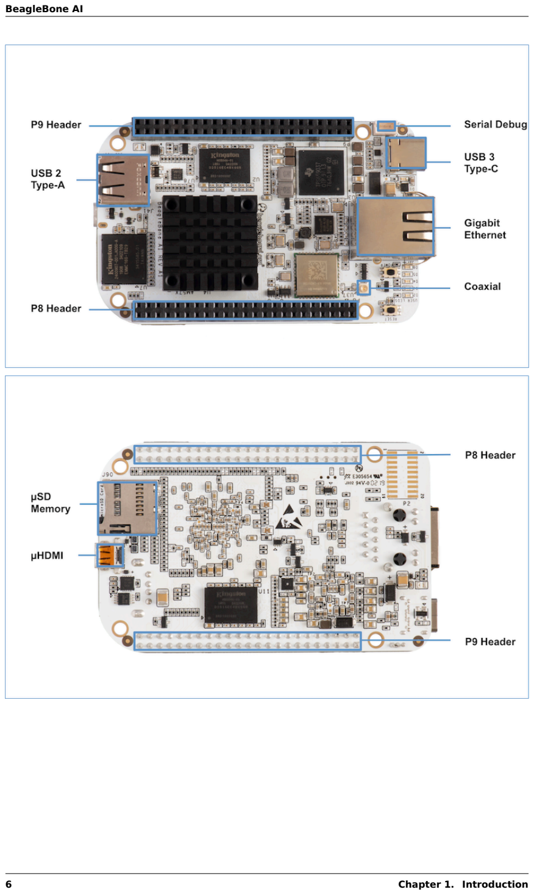
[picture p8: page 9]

### 6 Chapter 1. Introduction

# Chapter 2

# Quick start

## 2.1 What’s In the Box

BeagleBone® AI comes in the box with the heat sink and antenna already attached. Developers can get up and running in five minutes with no microSD card needed. BeagleBone® AI comes preloaded with a Linux distribution. In the box you will find:

- BeagleBone® AI (https://www.beagleboard.org/boards/beaglebone-ai)
- Quick Start Guide

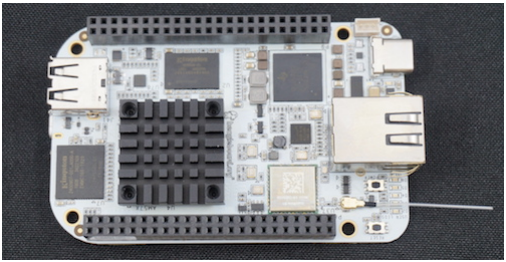
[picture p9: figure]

Tip: For board files, 3D model, regulatory docs and more, you can checkout BeagleBona-AI repository on OpenBeagle. (https://openbeagle.org/beagleboard/beaglebone-ai/)

## 2.2 What’s Not in the Box

You will need to purchase:

- USB C cable or USB C to USB A cable
- MicroSD Card (optional)

7

- Serial cable (optional)

More information or to purchase a replacement heat sink or antenna, please go to these websites:

- Antenna (https://bit.ly/2kmXAzF)
- Heat Sink (https://bit.ly/2klxxJa)

## 2.3 Fans

The pre-attached heat sink has M3 holes spaced 20x20 mm. The height of the heat sink clears the USB type A socket, and all other components on the board except the 46-way header sockets and the Ethernet socket.

If you run all of the accelerators or have an older software image, you’ll likely need fan. To find a fan, visit the link to fans in the FAQ. (https://git.beagleboard.org/beagleboard/beaglebone-ai/-/wikis/Frequently-Asked-Questions#fans)

Caution: BeagleBone AI can run HOT! Even without running the accelerators, getting up to 70C is not uncommon.

Read about Fan update for BeagleBone AI on Forum <https://forum.beagleboard.org/t/fan-update-for-beaglebone-ai/1964>.

1. Official BeagleBone Fan Cape (https://www.newark.com/element14/6100310/beaglebone-ai-fan-cape/dp/50AH3704)
2. Coolerguys | 25mm | (25x25x10) | USB | Fan | <https://www.coolerguys.com/en-in/collections/usb-
fans/products/25mm-25x25x10-usb-fan>

## 2.4 Main Connection Scenarios

This section will describe how to connect the board for use. The board can be configured in several different ways. Below we will walk through the most common scenarios. NOTE: These connection scenarios are depen-dent on the software image presently on your BeagleBone® AI. When all else fails, follow the instructions at Upgrade BeagleBone AI software.

- Tethered to a PC via USB C cable
- Standalone Desktop with powered USB hub, display, keyboard and mouse
- Wireless Connection to BeagleBone® AI

Tethered

Tethered to a PC

The most common way to program BeagleBone® AI is via a USB connection to a PC. If your computer has a USB C type port, BeagleBone® AI will both communicate and receive power directly from the PC. If your computer does not support USB C type, you can utilize a powered USB C hub to power and connect to BeagleBone® AI which in turn will connect to your PC. You can also use a powered USB C hub to power and connect peripheral devices such as a USB camera. After booting, the board is accessed either as a USB storage device or via the browser on the PC. You will need Chrome or Firefox on the PC.

Note: Start with this image “am57xx-eMMC-flasher-debian-10.3-iot-tidl-armhf-2020-04-06-6gb.img.xz” loaded on your BeagleBone® AI.

1. Locate the USB Type-C connector on BeagleBone® AI

### 8 Chapter 2. Quick start

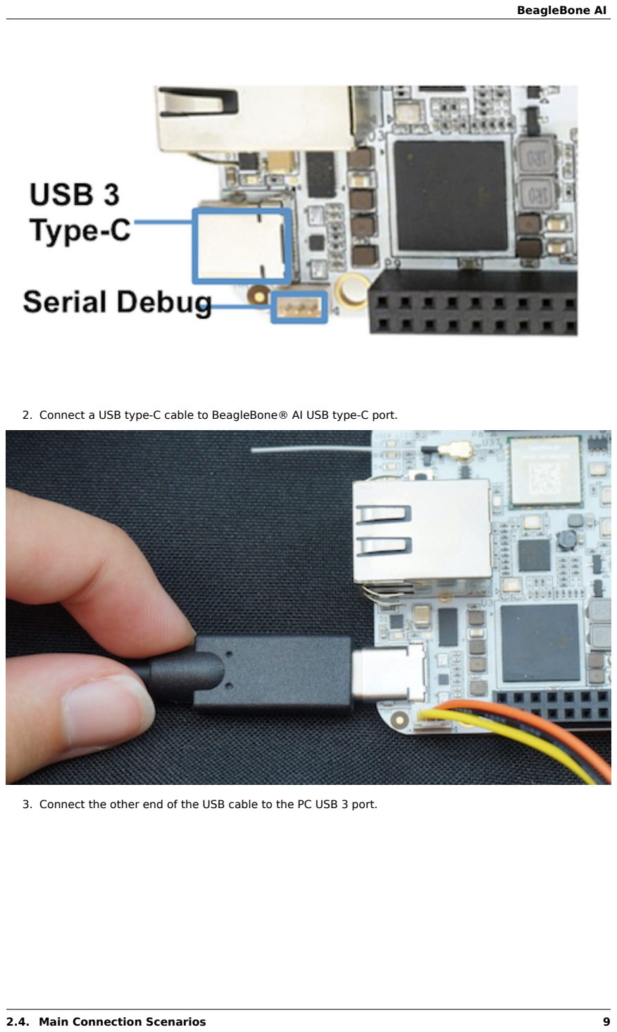
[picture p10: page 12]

2. Connect a USB type-C cable to BeagleBone® AI USB type-C port.
3. Connect the other end of the USB cable to the PC USB 3 port.
2.4. Main Connection Scenarios | 9

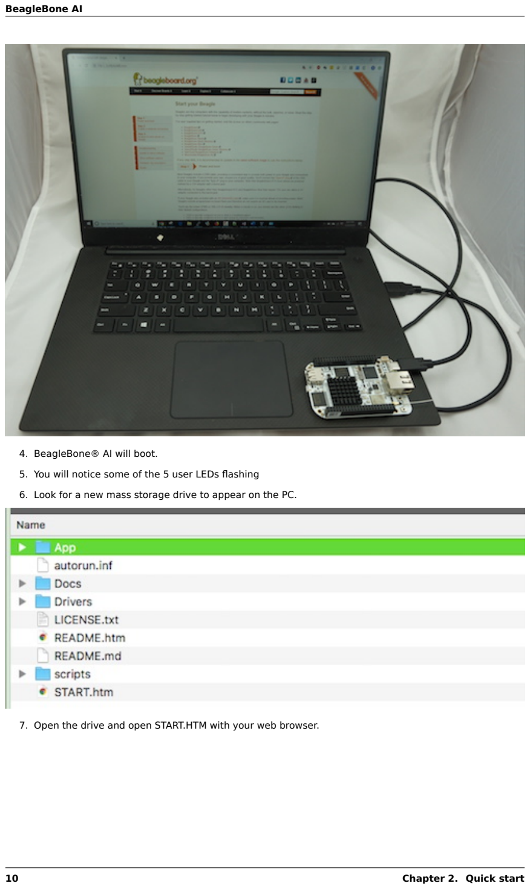
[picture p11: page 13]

4. BeagleBone® AI will boot.
5. You will notice some of the 5 user LEDs flashing
6. Look for a new mass storage drive to appear on the PC.
7. Open the drive and open START.HTM with your web browser.

### 10 Chapter 2. Quick start

8. Follow the instructions in the browser window.
2.4. Main Connection Scenarios | 11

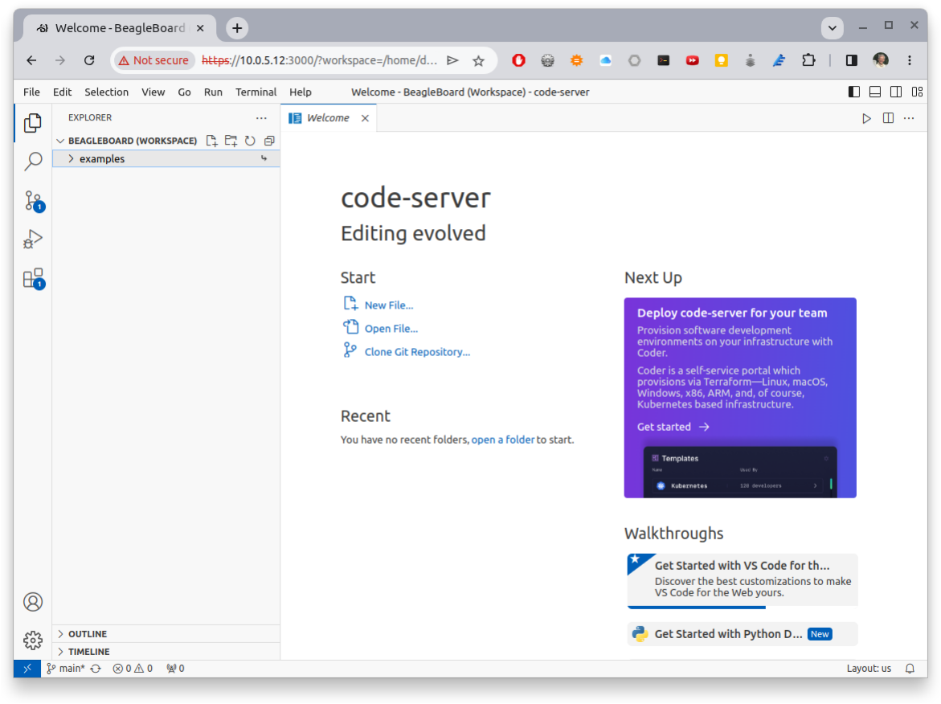
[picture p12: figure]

9. Go to Visual Studio Code IDE.

Standalone

Standalone w/Display and Keyboard/Mouse

### 12 Chapter 2. Quick start

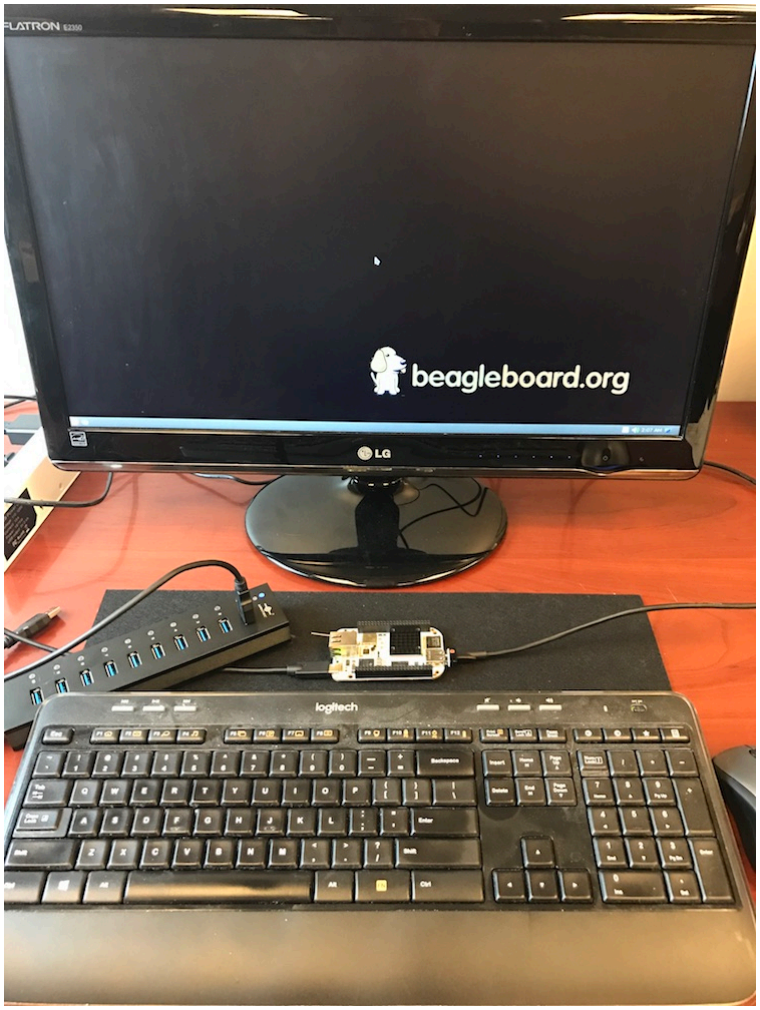
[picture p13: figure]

Note: This configuration requires loading the latest debian 9 image from https://elinux.org/Beagleboard: Latest-images-testing (https://elinux.org/Beagleboard:Latest-images-testing)

Load “am57xx-eMMC-flasher-debian-9.13-lxqt-tidl-armhf-2020-08-25-6gb.img.xz” image on the BeagleBone® AI

2.4. Main Connection Scenarios | 13

10. Connect a combo keyboard and mouse to BeagleBone® AI’s USB host port.
11. Connect a microHDMI-to-HDMI cable to BeagleBone® AI’s microHDMI port.
12. Connect the microHDMI-to-HDMI cable to an HDMI monitor.
13. Plug a 5V 3A USB type-C power supply into BeagleBone® AI’s USB type-C port.
14. BeagleBone® AI will boot. No need to enter any passwords.
15. Depending on which software image is loaded, either a Desktop or a login shell will appear on the monitor.
16. Follow the instructions at https://beagleboard.org/upgrade

Wireless

Wireless Connection

Note: Start with this image “am57xx-eMMC-flasher-debian-10.3-iot-tidl-armhf-2020-04-06-6gb.img.xz” loaded on your BeagleBone® AI.

17. Plug a 5V 3A USB type-C power supply into BeagleBone® AI’s USB type-C port.
18. BeagleBone® AI will boot.
19. Connect your PC’s WiFi to SSID “BeagleBone-XXXX” where XXXX varies for your BeagleBone® AI.
20. Use password “BeagleBone” to complete the WiFi connection.
21. Open http://192.168.8.1 in your web browser.
22. Follow the instructions in the browser window.

## 2.5 Connecting a 3 PIN Serial Debug Cable

A 3 PIN serial debug cable can be helpful to debug when you need to view the boot messages through a terminal program such as putty on your host PC. This cable is not needed for most BeagleBone® AI boot up scenarios.

Cables: | https://git.beagleboard.org/beagleboard/beaglebone-ai/-/wikis/Frequently-Asked-Questions#
serial-cable (https://git.beagleboard.org/beagleboard/beaglebone-ai/-/wikis/Frequently-Asked-Questions)

Locate the 3 PIN debug header on BeagleBone® AI, near the USB C connection.

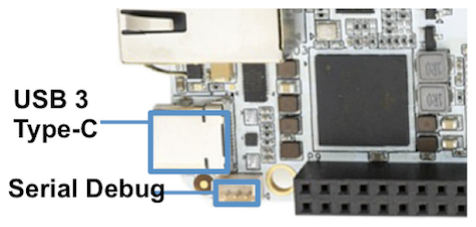
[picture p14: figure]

Press the small white connector into the 3 PIN debug header. The pinout is:

- Pin 1 (the pin closest to the screw-hole in the board. It is also marked with a shape on the silkscreen): GND
- Pin 2: UART1_RX (i.e. this is a BB-AI input pin)
- Pin 3: UART1_TX (i.e. BB-AI transmits out on this pin)

### 14 Chapter 2. Quick start

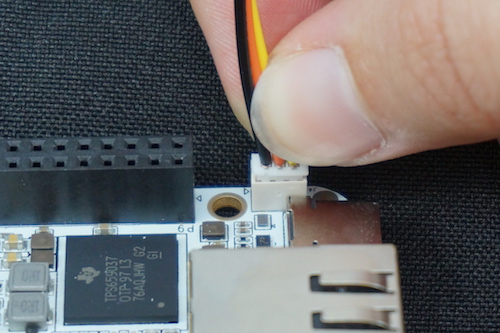
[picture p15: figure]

2.5. Connecting a 3 PIN Serial Debug Cable | 15

### 16 Chapter 2. Quick start

# Chapter 3

# Design and specifications

This section provides a detailed description of the Hardware design. This can be useful for interfacing, writing drivers, or using it to help modify specifics of your own design.

The figure below is the high level block diagram of BeagleBone® AI. For those who may be concerned, this is the same figure found in section 5. It is placed here again for convenience so it is closer to the topics to follow.

## 3.1 Block Diagram

The figure below is the high level block diagram of BeagleBone® AI. For detailed layout information please check the schematics.

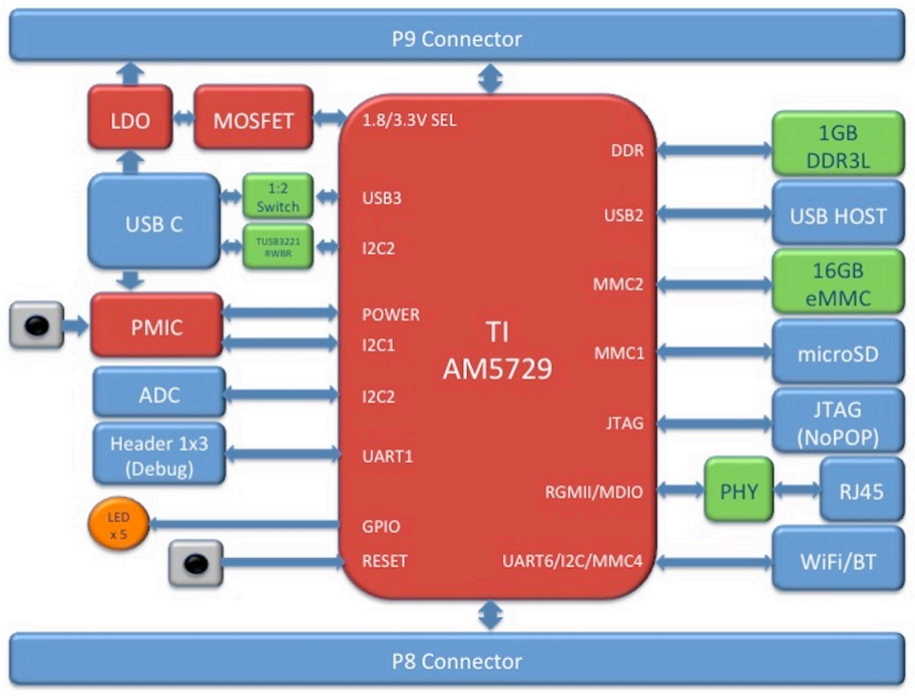
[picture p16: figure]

17

## 3.2 AM572x Sitara™ Processor

The Texas Instruments AM572x Sitara™ processor family of SOC devices brings high processing performance through the maximum flexibility of a fully integrated mixed processor solution. The devices also combine programmable video processing with a highly integrated peripheral set ideal for AI applications. The AM5729 used on BeagleBone® AI is the super-set device of the family.

Programmability is provided by dual-core ARM® Cortex®-A15 RISC CPUs with Arm® Neon™ extension, and two TI C66x VLIW floating-point DSP core, and Vision AccelerationPac (with 4x EVEs). The Arm allows developers to keep control functions separate from other algorithms programmed on the DSPs and coprocessors, thus reducing the complexity of the system software.

Texas Instruments AM572x Sitara™ Processor Family Block Diagram*

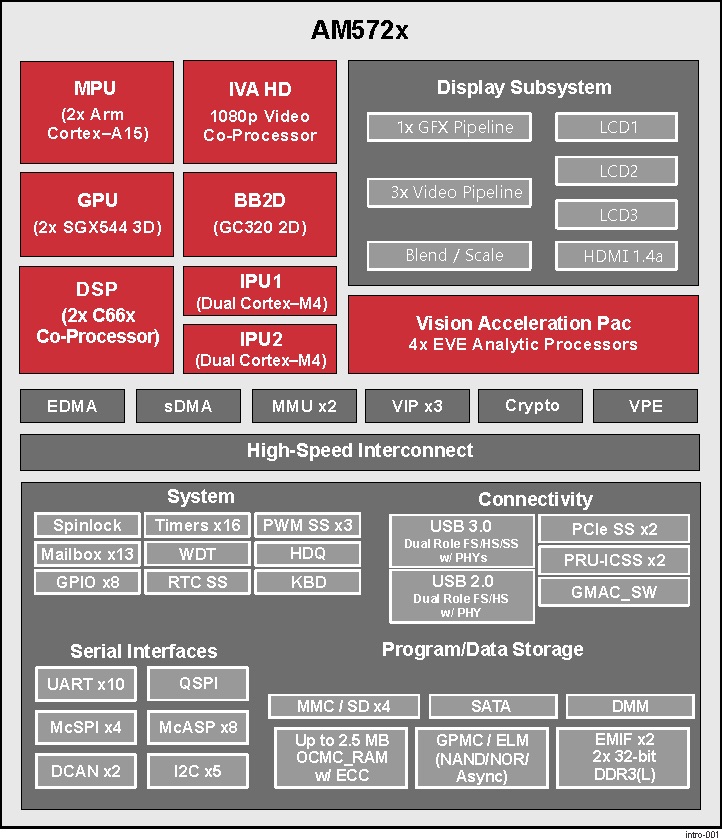
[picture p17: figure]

MPU Subsystem The Dual Cortex-A15 MPU subsystem integrates the following submodules:

### 18 Chapter 3. Design and specifications

- ARM Cortex-A15 MPCore

– Two central processing units (CPUs)

– ARM Version 7 ISA: Standard ARM instruction set plus Thumb®-2, Jazelle® RCT Java™ accelerator, hardware virtualization support, and large physical address extensions (LPAE)

– Neon™ SIMD coprocessor and VFPv4 per CPU

– Interrupt controller with up to 160 interrupt requests

– One general-purpose timer and one watchdog timer per CPU – Debug and trace features

– 32-KiB instruction and 32-KiB data level 1 (L1) cache per CPU

- Shared 2-MiB level 2 (L2) cache
- 48-KiB bootable ROM
- Local power, reset, and clock management (PRCM) module
- Emulation features
- Digital phase-locked loop (DPLL)

DSP Subsystems There are two DSP subsystems in the device. Each DSP subsystem contains the following submodules:

- TMS320C66x™ Floating-Point VLIW DSP core for audio processing, and general-purpose imaging and video processing. It extends the performance of existing C64x+™ and C647x™ DSPs through enhance-ments and new features.

– 32-KiB L1D and 32-KiB L1P cache or addressable SRAM

– 288-KiB L2 cache

- 256-KiB configurable as cache or SRAM
- 32-KiB SRAM
- Enhanced direct memory access (EDMA) engine for video and audio data transfer
- Memory management units (MMU) for address management.
- Interrupt controller (INTC)
- Emulation capabilities
- Supported by OpenCL

EVE Subsystems

- 4 Embedded Vision Engines (EVEs) supported by TIDL machine learning library
3.2. AM572x Sitara™ Processor | 19

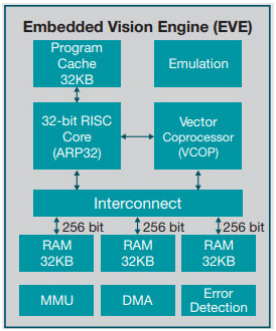
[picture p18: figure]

The Embedded Vision Engine (EVE) module is a programmable imaging and vision processing engine. Software support for the EVE module is available through OpenCL Custom Device model with fixed set of functions. More information is available http://www.ti.com/lit/wp/spry251/spry251.pdf

PRU-ICSS Subsystems

- 2x Dual-Core Programmable Real-Time Unit (PRU) subsystems (4 PRUs total) for ultra low-latency control and software generated peripherals. Access to these powerful subsystems is available through through the P8 and P9 headers. These are detailed in Section 7.

IPU Subsystems There are two Dual Cortex-M4 IPU subsystems in the device available for general purpose usage, particularly real-time control. Each IPU subsystem includes the following components:

- Two Cortex-M4 CPUs
- ARMv7E-M and Thumb-2 instruction set architectures
- Hardware division and single-cycle multiplication acceleration
- Dedicated INTC with up to 63 physical interrupt events with 16-level priority
- Two-level memory subsystem hierarchy

– L1 (32-KiB shared cache memory)

– L2 ROM + RAM

- 64-KiB RAM
- 16-KiB bootable ROM
- MMU for address translation
- Integrated power management
- Emulation feature embedded in the Cortex-M4

IVA-HD Subsystem

### 20 Chapter 3. Design and specifications

- IVA-HD subsystem with support for 4K @ 15fps H.264 encode/decode and other codecs @ 1080p60 The IVA-HD subsystem is a set of video encoder and decoder hardware accelerators. The list of supported codecs can be found in the software development kit (SDK) documentation.

BB2D Graphics Accelerator Subsystem The Vivante® GC320 2D graphics accelerator is the 2D BitBlt (BB2D) graphics accelerator subsystem on the device with the following features:

- API support:

– OpenWF™, DirectFB

– GDI/DirectDraw

- BB2D architecture:

– BitBlt and StretchBlt

– DirectFB hardware acceleration

– ROP2, ROP3, ROP4 full alpha blending and transparency

– Clipping rectangle support

– Alpha blending includes Java 2 Porter-Duff compositing rules

– 90-, 180-, 270-degree rotation on every primitive

– YUV-to-RGB color space conversion

– Programmable display format conversion with 14 source and 7 destination formats

– High-quality, 9-tap, 32-phase filter for image and video scaling at 1080p

– Monochrome expansion for text rendering

– 32K × 32K coordinate system

Dual-Core PowerVR® SGX544™ 3D GPU The 3D graphics processing unit (GPU) subsystem is based on POWERVR® SGX544 subsystem from Imagination Technologies. It supports general embedded applications. The GPU can process different data types simultaneously, such as: pixel data, vertex data, video data, and general-purpose data. The GPU subsystem has the following features:

- Multicore GPU architecture: two SGX544 cores.
- Shared system level cache of 128 KiB
- Tile-based deferred rendering architecture
- Second-generation universal scalable shader engines (USSE2), multithreaded engines incorporating pixel and vertex shader functionality
- Present and texture load accelerators

– Enables to move, rotate, twiddle, and scale texture surfaces.

– Supports RGB, ARGB, YUV422, and YUV420 surface formats.

– Supports bilinear upscale.

– Supports source colorkey.

- Fine-grained task switching, load balancing, and power management
- Programmable high-quality image antialiasing
- Bilinear, trilinear, anisotropic texture filtering
- Advanced geometry DMA driven operation for minimum CPU interaction
- Fully virtualized memory addressing for OS operation in a unified memory architecture (MMU)
3.2. AM572x Sitara™ Processor | 21

## 3.3 Memory

### 3.3.1 1GB DDR3L

Dual 256M x 16 DDR3L memory devices are used, one on each side of the board, for a total of 1 GB. They will each operate at a clock frequency of up to 533 MHz yielding an effective rate of 1066Mb/s on the DDR3L bus allowing for 4GB/s of DDR3L memory bandwidth.

### 3.3.2 16GB Embedded MMC

A single 16GB embedded MMC (eMMC) device is on the board.

### 3.3.3 microSD Connector

The board is equipped with a single microSD connector to act as a secondary boot source for the board and, if selected as such, can be the primary booth source. The connector will support larger capacity microSD cards. The microSD card is not provided with the board.

## 3.4 Boot Modes

## 3.5 Power Management

## 3.6 Connectivity

BeagleBone® AI supports the majority of the functions of the AM5729 SOC through connectors or expansion header pin accessibility. See section 7 for more information on expansion header pinouts. There are a few functions that are not accessible which are: (TBD)

Table 3.1: On-board I2C Devices

Address | Identifier | Description
0x12 | U3 | TPS6590379 PMIC DVS
0x41 | U78 | STMPE811Q ADC and GPIO expander
0x47 | U13 | HD3SS3220 USB Type-C DRP port controller
0x50 | U9 | 24LC32 board ID EEPROM
0x58 | U3 | TPS6590379 PMIC power registers
0x5a | U3 | TPS6590379 PMIC interfaces and auxiliaries
0x5c | U3 | TPS6590379 PMIC trimming and test
0x5e | U3 | TPS6590379 PMIC OTP

## 3.7 Power Section

Figure ? is the high level block diagram of the power section of the board.

(Block Diagram for Power)

### 3.7.1 TPS6590379 PMIC

The Texas Instruments TPS6590379ZWSR device is an integrated power-management IC (PMIC) specifically designed to work well ARM Cortex A15 Processors, such as the AM5729 used on BeagleBone® AI. The datasheet is located here https://www.ti.com/lit/ds/symlink/tps659037.pdf

### 22 Chapter 3. Design and specifications

The device provides seven configurable step-down converters with up to 6 A of output current for memory, processor core, input-output (I/O), or preregulation of LDOs. One of these configurable step-down converters can be combined with another 3-A regulator to allow up to 9 A of output current. All of the step-down converters can synchronize to an external clock source between 1.7 MHz and 2.7 MHz, or an internal fallback clock at 2.2 MHz.

The TPS659037 device contains seven LDO regulators for external use. These LDO regulators can be supplied from either a system supply or a preregulated supply. The power-up and power-down controller is configurable and supports any power-up and power-down sequences (OTP based). The TPS659037 device includes a 32-kHz RC oscillator to sequence all resources during power up and power down. In cases where a fast start up is needed, a 16-MHz crystal oscillator is also included to quickly generate a stable 32-kHz for the system. All LDOs and SMPS converters can be controlled by the SPI or I2C interface, or by power request signals. In addition, voltage scaling registers allow transitioning the SMPS to different voltages by SPI, I2C, or roof and floor control.

One dedicated pin in each package can be configured as part of the power-up sequence to control external resources. General-purpose input-output (GPIO) functionality is available and two GPIOs can be configured as part of the power-up sequence to control external resources. Power request signals enable power mode control for power optimization. The device includes a general-purpose sigma-delta analog-to-digital converter (GPADC) with three external input channels.

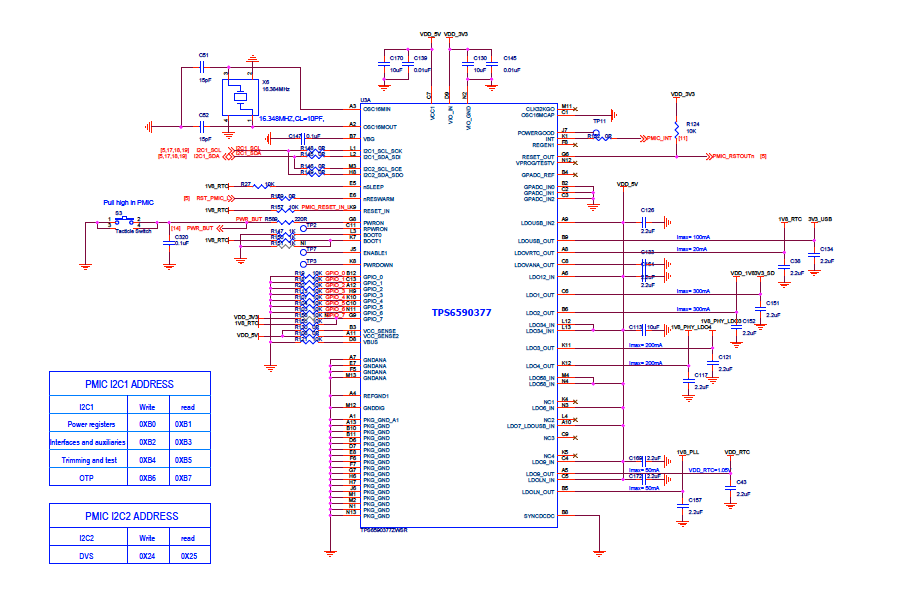
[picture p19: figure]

### 3.7.2 USB-C Power

Below image shows how the USB-C power input is connected to the TPS6590379.

3.7. Power Section | 23

### 3.7.3 Power Button

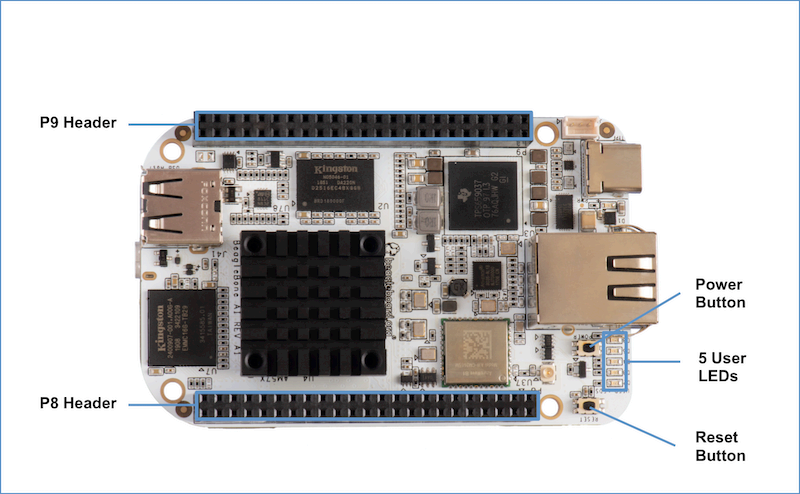
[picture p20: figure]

## 3.8 eMMC Flash Memory (16GB)

### 3.8.1 eMMC Device

### 3.8.2 eMMC Circuit Design

### 3.8.3 Board ID

A board identifier is placed on the eMMC in the second linear boot partition (/dev/mmcblk1boot1). Reserved bytes up to 32k (0x8000) are filled with “FF”.

Table 3.2: Board ID

Name | Size (bytes) | Contents
Header | 4 | MSB 0xEE3355AA LSB (stored LSB first)
Board Name | 8 | Name for board in ASCII “BBONE-AI” = BeagleBone AI
Version | 4 | Hardware version code for board in ASCII “00A1” = rev. A1
Serial Number | 14 | Serial number of the board. This is a 14 character string which is: WWYYEMAInnnnnn where: • WW = 2 digit week of the year of production • YY = 2 digit year of production • EM = Embest • AI = BeagleBone AI • nnnnnn = incrementing board number

### 24 Chapter 3. Design and specifications

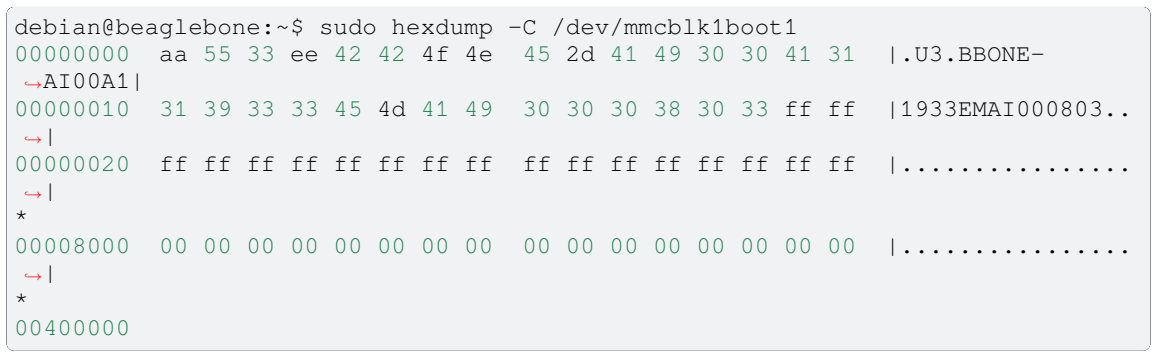
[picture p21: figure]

### debian@beaglebone:~$ sudo hexdump -C /dev/mmcblk1boot1 00000000 aa 55 33 ee 42 42 4f 4e 45 2d 41 49 30 30 41 31 |.U3.BBONE-

00000010 31 39 33 33 45 4d 41 49 30 30 30 38 30 33 ff ff |1933EMAI000803..

### 00000020 ff ff ff ff ff ff ff ff ff ff ff ff ff ff ff ff | |

00008000 00 00 00 00 00 00 00 00 00 00 00 00 00 00 00 00 | |

## 3.9 Wireless Communication: 802.11 ac & Bluetooth: AzureWave AW-CM256SM

Datasheet https://storage.googleapis.com/wzukusers/user-26561200/documents/5b7d0fe3c3f29Ct6k0QI/AW-CM256SM_DS_Rev%2015_CYW.pdf (https://storage.googleapis.com/wzukusers/user-26561200/documents/5b7d0fe3c3f29Ct6k0QI/AW-CM256SM_DS_Rev%2015_CYW.pdf) Wireless connectivity is provided on BeagleBone® AI via the Azure-Wave Technologies AW-CM256SM IEEE 802.11a/b/g/n/ac Wi-Fi with Bluetooth 4.2 Combo Stamp Module.

This highly integrated wireless local area network (WLAN) solution combines Bluetooth 4.2 and provides a complete 2.4GHz Bluetooth system which is fully compliant to Bluetooth 4.2 and v2.1 that supports EDR of 2Mbps and 3Mbps for data and audio communications. It enables a high performance, cost effective, low power, compact solution that easily fits onto the SDIO and UART combo stamp module.

Compliant with the IEEE 802.11a/b/g/n/ac standard, AW-CM256SM uses Direct Sequence Spread Spectrum (DSSS), Orthogonal Frequency Division Multiplexing (OFDM), BPSK, QPSK, CCK and QAM baseband modulation technologies. Compare to 802.11n technology, 802.11ac provides a big improvement on speed and range.

The AW-CM256SM module adopts a Cypress solution. The module design is based on the Cypress CYP43455 single chip.

### 3.9.1 WLAN on the AzureWave AW-CM256SM

High speed wireless connection up to 433.3Mbps transmit/receive PHY rate using 80MHz bandwidth,

- 1 antennas to support 1(Transmit) and 1(Receive) technology and Bluetooth
- WCS (Wireless Coexistence System)
- Low power consumption and high performance
- Enhanced wireless security
- Fully speed operation with Piconet and Scatternet support
- 12mm(L) x 12mm(W) x1.65mm(H) LGA package
- Dual - band 2.4 GHz and 5GHz 802.11 a/b/g/n/ac
- External Crystal

### 3.9.2 Bluetooth on the AzureWave AW-CM256S

- 1 antennas to support 1(Transmit) and 1(Receive) technology and Bluetooth
- Fully qualified Bluetooth BT4.2
- Enhanced Data Rate(EDR) compliant for both 2Mbps and 3Mbps supported
- High speed UART and PCM for Bluetooth
3.9. Wireless Communication: 802.11 ac & Bluetooth: AzureWave AW-CM256SM | 25

## 3.10 HDMI

The HDMI interface is aligned with the HDMI TMDS single stream standard v1.4a (720p @60Hz to 1080p @24Hz) and the HDMI v1.3 (1080p @60Hz): 3 data channels, plus 1 clock channel is supported (differential).

## 3.11 PRU-ICSS

The Texas Instruments AM5729 Sitara™ provides 2 Programmable Real-Time Unit Subsystem and Industrial Communciation Subsystems. (PRU-ICSS1 and PRU-ICSS2).

Within each PRU-ICSS are dual 32-bit Load / Store RISC CPU cores: Programmable Real-Time Units (PRU0 and PRU1), shared data and instruction memories, internal peripheral modules and an interrupt controller. Therefore the SoC is providing a total of 4 PRU 32-bit RISC CPU’s:

- PRU-ICSS1 PRU0
- PRU-ICSS1 PRU1
- PRU-ICSS2 PRU0
- PRU-ICSS2 PRU1

The programmable nature of the PRUs, along with their access to pins, events and all SoC resources, provides flexibility in implementing fast real-time responses, specialized data handling operations, peripheral interfaces and in off-loading tasks from the other processor cores of the SoC.

### 3.11.1 PRU-ICSS Features

Each of the 2 PRU-ICSS (PRU-ICSS1 and PRU-ICSS2) includes the following main features:

- 2 Independent programmable real-time (PRU) cores (PRU0 and PRU1)
- 21x Enhanced GPIs (EGPIs) and 21x Enhanced GPOs (EGPOs) with asynchronous capture and serial support per each PRU CPU core
- One Ethernet MII_RT module (PRU-ICSS_MII_RT) with two MII ports and configurable connections to PRUs
- 1 MDIO Port (PRU-ICSS_MII_MDIO)
- One Industrial Ethernet Peripheral (IEP) to manage/generate Industrial Ethernet functions
- 1 x 16550-compatible UART with a dedicated 192 MHz clock to support 12Mbps Profibus
- 1 Industrial Ethernet timer with 7/9 capture and 8 compare events
- 1 Enhanced Capture Module (ECAP)
- 1 Interrupt Controller (PRU-ICSS_INTC)
- A flexible power management support
- Integrated switched central resource with programmable priority
- Parity control supported by all memories

### 3.11.2 PRU-ICSS Block Diagram

Below is a high level block diagram of one of the PRU-ICSS Subsystems

### 26 Chapter 3. Design and specifications

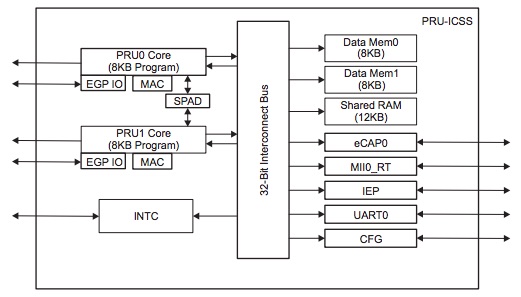
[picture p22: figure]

## 3.12 PRU-ICSS Resources and FAQ’s

Resources

- Great resources for PRU and BeagleBone® has been compiled here https://beagleboard.org/pru
- The PRU Cookbook provides examples and getting started information pru-cookbook-home
- Detailed specification is available at http://processors.wiki.ti.com/index.php/PRU-ICSS

FAQ

- Q: Is it possible to configure the Ethernet MII to be accessed via a PRU MII?
- A: TBD

### 3.12.1 PRU-ICSS1 Pin Access

The table below shows which PRU-ICSS1 signals can be accessed on BeagleBone® AI and on which connector and pins they are accessible from. Some signals are accessible on the same pins. Signal Names reveal which PRU-ICSS Subsystem is being addressed. pr1 is PRU-ICSS1 and pr2 is PRU-ICSS2

3.12. PRU-ICSS Resources and FAQ’s | 27

BeagleBone AI Table 3.3: PRU⁻ICSS1 Pin Access | SIGNAL NAME DESCRIPTION T Y P E P R O C HE ADER _PIN M O D E HE ADER _PIN M O D E | pr1_pru0_gpo0 PRU⁰ G eneral-Purpose Output

O A H 6 NA

pr1_pru0_gpo1 PRU0 G eneral-Purpose Output

O A H 3 NA

pr1_pru0_gpo2 PRU0 G eneral-Purpose Output

O A H 5 NA

pr1_pru0_gpo3 PRU0 G eneral-Purpose Output

O A G 6 P 8_12 M O D E 1 3

pr1_pru0_gpo4 PRU0 G eneral-Purpose Output

O A H 4 P 8_11 M O D E 1 3

pr1_pru0_gpo5 PRU0 G eneral-Purpose Output

O A G 4 P 9_15 M O D E 1 3

pr1_pru0_gpo6 PRU0 G eneral-Purpose Output

O A G 2 NA

pr1_pru0_gpo7 PRU0 G eneral-Purpose Output

O A G 3 NA

pr1_pru0_gpo8 PRU0 G eneral-Purpose Output

O A G 5 NA

pr1_pru0_gpo9 PRU0 G eneral-Purpose Output

O A F 2 NA

pr1_pru0_gpo10 PRU0 G eneral-Purpose Output

O A F 6 NA

pr1_pru0_gpo11 PRU0 G eneral-Purpose Output

O A F 3 NA

pr1_pru0_gpo12 PRU0 G eneral-Purpose Output

O A F 4 NA

pr1_pru0_gpo13 PRU0 G eneral-Purpose Output

O A F 1 NA

pr1_pru0_gpo14 PRU0 G eneral-Purpose Output

O A E 3 NA

pr1_pru0_gpo15 PRU0 G eneral-Purpose Output

O A E 5 NA

pr1_pru0_gpo16 PRU0 G eneral-Purpose Output

O A E 1 NA

pr1_pru0_gpo17 PRU0 G eneral-Purpose Output

O A E 2 P 9_26 M O D E 1 3

pr1_pru0_gpo18 PRU0 G eneral-Purpose Output

O A E 6 NA

pr1_pru0_gpo19 PRU0 G eneral-Purpose Output

O A D 2 NA

pr1_pru0_gpo20 PRU0 G eneral-Purpose Output

O A D 3 NA

pr1_pru0_gpi0 PRU0 G eneral-Purpose Input I A H 6 NA

pr1_pru0_gpi1 PRU0 G eneral-Purpose Input I A H 3 NA

pr1_pru0_gpi2 PRU0 G eneral-Purpose Input I A H 5 NA pr1_pru0_gpi3 PRU0 G eneral-Purpose Input I A G 6 P 8_12 M O D E 1 2

pr1_pru0_gpi4 PRU0 G eneral-Purpose Input I A H 4 P 8_11 M O D E 1 2

pr1_pru0_gpi5 PRU0 G eneral-Purpose Input I A G 4 P 9_15 M O D E 1 2

pr1_pru0_gpi6 PRU0 G eneral-Purpose Input I A G 2 NA

pr1_pru0_gpi7 PRU0 G eneral-Purpose Input I A G 3 NA

pr1_pru0_gpi8 PRU0 G eneral-Purpose Input I A G 5 NA

pr1_pru0_gpi9 PRU0 G eneral-Purpose Input I A F 2 NA

pr1_pru0_gpi10 PRU0 G eneral-Purpose Input I A F 6 NA

pr1_pru0_gpi11 PRU0 G eneral-Purpose Input I A F 3 NA

pr1_pru0_gpi12 PRU0 G eneral-Purpose Input I A F 4 NA

pr1_pru0_gpi13 PRU0 G eneral-Purpose Input I A F 1 NA

pr1_pru0_gpi14 PRU0 G eneral-Purpose Input I A E 3 NA

continues on next page

### 28 Chapter 3. Design and specifications

Table 3.3 – continued from previous page

SIGNAL NAME DESCRIPTION T Y P E P R O C HE ADER _PIN M O D E HE ADER _PIN M O D E

pr1_pru0_gpi15 PRU0 G eneral-Purpose Input I A E 5 NA

pr1_pru0_gpi16 PRU0 G eneral-Purpose Input I A E 1 NA

pr1_pru0_gpi17 PRU0 G eneral-Purpose Input I A E 2 P 9_26 M O D E 1 2

pr1_pru0_gpi18 PRU0 G eneral-Purpose Input I A E 6 NA

pr1_pru0_gpi19 PRU0 G eneral-Purpose Input I A D 2 NA

pr1_pru0_gpi20 PRU0 G eneral-Purpose Input I A D 3 NA

pr1_pru1_gpo0 PRU1 G eneral-Purpose Output

O E 2 NA

pr1_pru1_gpo1 PRU1 G eneral-Purpose Output

O D 2 P 9_20 M O D E 1 3

pr1_pru1_gpo2 PRU1 G eneral-Purpose Output

O F 4 P 9_19 M O D E 1 3

pr1_pru1_gpo3 PRU1 G eneral-Purpose Output

O C 1 P 9_41 M O D E 1 3

pr1_pru1_gpo4 PRU1 G eneral-Purpose Output

O E 4 NA

pr1_pru1_gpo5 PRU1 G eneral-Purpose Output

O F 5 P 8_18 M O D E 1 3

pr1_pru1_gpo6 PRU1 G eneral-Purpose Output

O E 6 P 8_19 M O D E 1 3

pr1_pru1_gpo7 PRU1 G eneral-Purpose Output

O D 3 P 8_13 M O D E 1 3

pr1_pru1_gpo8 PRU1 G eneral-Purpose Output

O F 6 NA

pr1_pru1_gpo9 PRU1 G eneral-Purpose Output

O D 5 P 8_14 M O D E 1 3

pr1_pru1_gpo10 PRU1 G eneral-Purpose Output

O C 2 P 9_42 M O D E 1 3

pr1_pru1_gpo11 PRU1 G eneral-Purpose Output

O C 3 P 9_27 M O D E 1 3

pr1_pru1_gpo12 PRU1 G eneral-Purpose Output

O C 4 NA

pr1_pru1_gpo13 PRU1 G eneral-Purpose Output

O B 2 NA

pr1_pru1_gpo14 PRU1 G eneral-Purpose Output

O D 6 P 9_14 M O D E 1 3

pr1_pru1_gpo15 PRU1 G eneral-Purpose Output

O C 5 P 9_16 M O D E 1 3

pr1_pru1_gpo16 PRU1 G eneral-Purpose Output

O A 3 P 8_15 M O D E 1 3

pr1_pru1_gpo17 PRU1 G eneral-Purpose Output

O B 3 P 8_26 M O D E 1 3

pr1_pru1_gpo18 PRU1 G eneral-Purpose Output

O B 4 P 8_16 M O D E 1 3

pr1_pru1_gpo19 PRU1 G eneral-Purpose Output

O B 5 NA

pr1_pru1_gpo20 PRU1 G eneral-Purpose Output

O A 4 NA

pr1_pru1_gpi0 PRU1 G eneral-Purpose Input I E 2 NA pr1_pru1_gpi1 PRU1 G eneral-Purpose Input I D 2 P 9_20 M O D E 1 2

pr1_pru1_gpi2 PRU1 G eneral-Purpose Input I F 4 P 9_19 M O D E 1 2

pr1_pru1_gpi3 PRU1 G eneral-Purpose Input I C 1 P 9_41 M O D E 1 2

pr1_pru1_gpi4 PRU1 G eneral-Purpose Input I E 4 NA pr1_pru1_gpi5 PRU1 G eneral-Purpose Input I F 5 P 8_18 M O D E 1 2

pr1_pru1_gpi6 PRU1 G eneral-Purpose Input I E 6 P 8_19 M O D E 1 2

pr1_pru1_gpi7 PRU1 G eneral-Purpose Input I D 3 P 8_13 M O D E 1 2

pr1_pru1_gpi8 PRU1 G eneral-Purpose Input I F 6 NA pr1_pru1_gpi9 PRU1 G eneral-Purpose Input I D 5 P 8_14 M O D E 1 2

continues on next page

3.12. PRU-ICSS Resources and FAQ’s | 29

BeagleBone AI Table 3.3 ⁻ continued from previous page | SIGNAL NAME DESCRIPTION T Y P E P R O C HE ADER _PIN M O D E HE ADER _PIN M O D E | pr1_pru1_gpi10 PRU¹ G eneral-Purpose Input I C 2 P 9_42 M O D E 1 2 | pr1_pru1_gpi11 PRU¹ G eneral-Purpose Input I C 3 P 9_27 M O D E 1 2 | pr1_pru1_gpi12 PRU¹ G eneral-Purpose Input I C 4 NA | pr1_pru1_gpi13 PRU¹ G eneral-Purpose Input I B 2 NA

pr1_pru1_gpi14 PRU1 G eneral-Purpose Input I D 6 P 9_14 M O D E 1 2

pr1_pru1_gpi15 PRU1 G eneral-Purpose Input I C 5 P 9_16 M O D E 1 2

pr1_pru1_gpi16 PRU1 G eneral-Purpose Input I A 3 P 8_15 M O D E 1 2

pr1_pru1_gpi17 PRU1 G eneral-Purpose Input I B 3 P 8_26 M O D E 1 2

pr1_pru1_gpi18 PRU1 G eneral-Purpose Input I B 4 P 8_16 M O D E 1 2

pr1_pru1_gpi19 PRU1 G eneral-Purpose Input I B 5 NA

pr1_pru1_gpi20 PRU1 G eneral-Purpose Input I A 4 NA

pr1_mii_mt0_clk MII0 Transmit Clock I U 5 NA

pr1_mii0_txen MII0 Transmit Enable

O V 3 NA

pr1_mii0_txd3 MII0 Transmit Data

O V 5 NA

pr1_mii0_txd2 MII0 Transmit Data

O V 4 NA

pr1_mii0_txd1 MII0 Transmit Data

O Y 2 NA

pr1_mii0_txd0 MII0 Transmit Data

O W 2 NA

pr1_mii0_rxdv MII0 Data Valid I V 2 NA

pr1_mii_mr0_clk MII0 Receive Clock I Y 1 NA

pr1_mii0_rxd3 MII0 Receive Data I W 9 NA

pr1_mii0_rxd2 MII0 Receive Data I V 9 NA

pr1_mii0_crs MII0 Carrier Sense I V 7 NA

pr1_mii0_rxer MII0 Receive Error I U 7 NA

pr1_mii0_rxd1 MII0 Receive Data I V 6 NA

pr1_mii0_rxd0 MII0 Receive Data I U 6 NA

pr1_mii0_col MII0 Collision Detect I V 1 NA

pr1_mii0_rxlink MII0 Receive Link I U 4 NA

pr1_mii_mt1_clk MII1 Transmit Clock I C 1 P 9_41 M O D E 1 1

pr1_mii1_txen MII1 Transmit Enable

O E 4 NA

pr1_mii1_txd3 MII1 Transmit Data

O F 5 P 8_18 M O D E 1 1

pr1_mii1_txd2 MII1 Transmit Data

O E 6 P 8_19 M O D E 1 1

pr1_mii1_txd1 MII1 Transmit Data

O D 5 P 8_14 M O D E 1 1

pr1_mii1_txd0 MII1 Transmit Data

O C 2 P 9_42 M O D E 1 1

pr1_mii_mr1_clk MII1 Receive Clock I C 3 P 9_27 M O D E 1 1

pr1_mii1_rxdv MII1 Data Valid I C 4 NA

pr1_mii1_rxd3 MII1 Receive Data I B 2 NA pr1_mii1_rxd2 MII1 Receive Data I D 6 P 9_14 M O D E 1 1

continues on next page

### 30 Chapter 3. Design and specifications

Table 3.3 – continued from previous page

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

pr1_mii1_rxd1 MII1 Receive Data I C 5 P 9_16 M O D E 1 1

pr1_mii1_rxd0 MII1 Receive Data I A 3 P 8_15 M O D E 1 1

pr1_mii1_rxer MII1 Receive Error I B 3 P 8_26 M O D E 1 1

pr1_mii1_rxlink MII1 Receive Link I B 4 P 8_16 M O D E 1 1

pr1_mii1_col MII1 Collision Detect I B 5 NA

pr1_mii1_crs MII1 Carrier Sense I A 4 NA

pr1_mdio_mdclk MDIO Clock

O D 3 P 8_13 M O D E 1 1

pr1_mdio_data MDIO Data I O F 6 NA

pr1_edc_latch0_in Latch Input 0 I A G 3 / E 2 NA

pr1_edc_latch1_in Latch Input 1 I A G 5 NA

pr1_edc_sync0_out SYNC0 Output

O A F 2 / D 2 P 9_20 M O D E 1 1

pr1_edc_sync1_out SYNC1 Output

O A F 6 NA

pr1_edio_latch_in Latch Input I A F 3 NA

pr1_edio_sof Start Of Frame

O A F 4 / F 4 P 9_19 M O D E 1 1

pr1_edio_data_in0 Ethernet Digital Input I A F 1 / E 1 NA

pr1_edio_data_in1 Ethernet Digital Input I A E 3 / G 2 NA

pr1_edio_data_in2 Ethernet Digital Input I A E 5 / H 7 NA

pr1_edio_data_in3 Ethernet Digital Input I A E 1 / G 1 NA

pr1_edio_data_in4 Ethernet Digital Input I A E 2 / G 6 P 9_26 M O D E 1 0 P 8_34 M O D E 1 2

pr1_edio_data_in5 Ethernet Digital Input I A E 6 / F 2 P 8_36 M O D E 1 2

pr1_edio_data_in6 Ethernet Digital Input I A D 2 / F 3 NA

pr1_edio_data_in7 Ethernet Digital Input I A D 3 / D 1 P 8_15 M O D E 1 2

p r1_edio_data_out0 Ethernet Digital Output

O A F 1 / E 1 NA

p r1_edio_data_out1 Ethernet Digital Output

O A E 3 / G 2 NA

p r1_edio_data_out2 Ethernet Digital Output

O A E 5 / H 7 NA

p r1_edio_data_out3 Ethernet Digital Output

O A E 1 / G 1 NA

p r1_edio_data_out4 Ethernet Digital Output

O A E 2 / G 6 P 9_26 M O D E 1 1 P 8_34 M O D E 1 3

p r1_edio_data_out5 Ethernet Digital Output

O A E 6 / F 2 P 8_36 M O D E 1 3

p r1_edio_data_out6 Ethernet Digital Output

O A D 2 / F 3 NA

p r1_edio_data_out7 Ethernet Digital Output

O A D 3 / D 1 P 8_15 M O D E 1 3

pr1_uart0_cts_n UART Clear-To-Send I G 1 / F 1 1 P 8_45 M O D E 1 0

pr1_uart0_rts_n UART Ready-To-Send

O G 6 / G 1 0 P 8_34 M O D E 1 1 P 8_46 M O D E 1 0

pr1_uart0_rxd UART Receive Data I F 2 / F 1 0 P 8_36 M O D E 1 1 P 8_43 M O D E 1 0

pr1_uart0_txd UART Transmit Data

O F 3 / G 1 1 P 8_44 M O D E 1 0 pr1_ecap0_ ecap_capin_apwm_o Capture Input/PWM Output I O D 1 / E 9 P 8_15 M O D E 1 1 P 8_41 M O D E 1 0

3.12. PRU-ICSS Resources and FAQ’s | 31

### 3.12.2 PRU-ICSS2 Pin Access

The table below shows which PRU-ICSS2 signals can be accessed on BeagleBone® AI and on which connector and pins they are accessible from. Some signals are accessible on the same pins. Signal Names reveal which PRU-ICSS Subsystem is being addressed. pr1 is PRU-ICSS1 and pr2 is PRU-ICSS2

### 32 Chapter 3. Design and specifications

Table 3.4: PRU-ICSS2 Pin Access

SIGNAL NAME DESCR IPTION TYPE PROC HEAD ER_PIN MODE HEAD ER_PIN MODE

p r2_pru 0_gpo0 PRU0 Gen eral-P urpose Output

O G 11/AC5 P8_44 MODE13

p r2_pru 0_gpo1 PRU0 Gen eral-P urpose Output

O E9/AB4 P8_41 MODE13

p r2_pru 0_gpo2 PRU0 Gen eral-P urpose Output

O F9/AD4 P8_42 MODE13 P8_21 MODE13

p r2_pru 0_gpo3 PRU0 Gen eral-P urpose Output

O F8/AC4 P8_39 MODE13 P8_20 MODE13

p r2_pru 0_gpo4 PRU0 Gen eral-P urpose Output

O E7/AC7 P8_40 MODE13 P8_25 MODE13

p r2_pru 0_gpo5 PRU0 Gen eral-P urpose Output

O E8/AC6 P8_37 MODE13 P8_24 MODE13

p r2_pru 0_gpo6 PRU0 Gen eral-P urpose Output

O D9/AC9 P8_38 MODE13 P8_5 MODE13

p r2_pru 0_gpo7 PRU0 Gen eral-P urpose Output

O D7/AC3 P8_36 MODE13 P8_6 MODE13

p r2_pru 0_gpo8 PRU0 Gen eral-P urpose Output

O D8/AC8 P8_34 MODE13 P8_23 MODE13

p r2_pru 0_gpo9 PRU0 Gen eral-P urpose Output

O A5/AD6 P8_35 MODE13 P8_22 MODE13

pr 2_pru0 _gpo10 PRU0 Gen eral-P urpose Output

O C6/AB8 P8_33 MODE13 P8_3 MODE13

pr 2_pru0 _gpo11 PRU0 Gen eral-P urpose Output

O C8/AB5 P8_31 MODE13 P8_4 MODE13

pr 2_pru0 _gpo12 PRU0 Gen eral-P urpose Output

O C7/B18 P8_32 MODE13

pr 2_pru0 _gpo13 PRU0 Gen eral-P urpose Output

O B7/F15 P8_45 MODE13

pr 2_pru0 _gpo14 PRU0 Gen eral-P urpose Output

O B8/B19 P9_11 MODE13 P9_11 MODE13

pr 2_pru0 _gpo15 PRU0 Gen eral-P urpose Output

O A7/C17 P8_17 MODE13 P9_13 MODE13

pr 2_pru0 _gpo16 PRU0 Gen eral-P urpose Output

O A8/C15 P8_27 MODE13

pr 2_pru0 _gpo17 PRU0 Gen eral-P urpose Output

O C9/A16 P8_28 MODE13

pr 2_pru0 _gpo18 PRU0 Gen eral-P urpose Output

O A9/A19 P8_29 MODE13

pr 2_pru0 _gpo19 PRU0 Gen eral-P urpose Output

O B9/A18 P8_30 MODE13

pr 2_pru0 _gpo20 PRU0 Gen eral-P urpose Output

O A 10/F14 P8_46 MODE13 P8_8 MODE13

p r2_pru 0_gpi0 PRU0 Gen eral-P urpose Input I G 11/AC5 P8_44 MODE12

p r2_pru 0_gpi1 PRU0 Gen eral-P urpose Input I E9/AB4 P8_41 MODE12 p r2_pru 0_gpi2 PRU0 Gen eral-P urpose Input I F9/AD4 P8_42 MODE12 P8_21 MODE12

p r2_pru 0_gpi3 PRU0 Gen eral-P urpose Input I F8/AC4 P8_39 MODE12 P8_20 MODE12

p r2_pru 0_gpi4 PRU0 Gen eral-P urpose Input I E7/AC7 P8_40 MODE12 P8_25 MODE12

p r2_pru 0_gpi5 PRU0 Gen eral-P urpose Input I E8/AC6 P8_37 MODE12 P8_24 MODE12

p r2_pru 0_gpi6 PRU0 Gen eral-P urpose Input I D9/AC9 P8_38 MODE12 P8_5 MODE12

p r2_pru 0_gpi7 PRU0 Gen eral-P urpose Input I D7/AC3 P8_36 MODE12 P8_6 MODE12

p r2_pru 0_gpi8 PRU0 Gen eral-P urpose Input I D8/AC8 P8_34 MODE12 P8_23 MODE12

p r2_pru 0_gpi9 PRU0 Gen eral-P urpose Input I A5/AD6 P8_35 MODE12 P8_22 MODE12

pr 2_pru0 _gpi10 PRU0 Gen eral-P urpose Input I C6/AB8 P8_33 MODE12 P8_3 MODE12

pr 2_pru0 _gpi11 PRU0 Gen eral-P urpose Input I C8/AB5 P8_31 MODE12 P8_4 MODE12

pr 2_pru0 _gpi12 PRU0 Gen eral-P urpose Input I C7/B18 P8_32 MODE12

pr 2_pru0 _gpi13 PRU0 Gen eral-P urpose Input I B7/F15 P8_45 MODE12 pr 2_pru0 _gpi14 PRU0 Gen eral-P urpose Input I B8/B19 P9_11 MODE12 P9_11 MODE12
continues on next page
3.12. PRU-ICSS Resources and FAQ’s | 33

BeagleBone AI Table 3.4 ⁻ continued from previous page | SIGNAL NAME DESCR IPTION TYPE PROC HEAD ER_PIN MODE HEAD ER_PIN MODE | pr 2_pru0 _gpi15 PRU⁰ Gen eral-P urpose Input I A7/C17 P8_17 MODE12 P9_13 MODE12 | pr 2_pru0 _gpi16 PRU⁰ Gen eral-P urpose Input I A8/C15 P8_27 MODE12 | pr 2_pru0 _gpi17 PRU⁰ Gen eral-P urpose Input I C9/A16 P8_28 MODE12 | pr 2_pru0 _gpi18 PRU⁰ Gen eral-P urpose Input I A9/A19 P8_29 MODE12

pr 2_pru0 _gpi19 PRU0 Gen eral-P urpose Input I B9/A18 P8_30 MODE12

pr 2_pru0 _gpi20 PRU0 Gen eral-P urpose Input I A 10/F14 P8_46 MODE12 P8_8 MODE12

p r2_pru 1_gpo0 PRU1 Gen eral-P urpose Output

O V1/D17 P8_32 MODE13

p r2_pru 1_gpo1 PRU1 Gen eral-P urpose Output

O U4/AA3 NA

p r2_pru 1_gpo2 PRU1 Gen eral-P urpose Output

O U3/AB9 NA

p r2_pru 1_gpo3 PRU1 Gen eral-P urpose Output

O V2/AB3 NA

p r2_pru 1_gpo4 PRU1 Gen eral-P urpose Output

O Y1/AA4 NA

p r2_pru 1_gpo5 PRU1 Gen eral-P urpose Output

O W9/D18 P9_25 MODE13

p r2_pru 1_gpo6 PRU1 Gen eral-P urpose Output

O V9/E17 P8_9 MODE13

p r2_pru 1_gpo7 PRU1 Gen eral-P urpose Output

O V7/C14 P9_31 MODE13

p r2_pru 1_gpo8 PRU1 Gen eral-P urpose Output

O U7/G12 P9_18 MODE13

p r2_pru 1_gpo9 PRU1 Gen eral-P urpose Output

O V6/F12 P9_17 MODE13

pr 2_pru1 _gpo10 PRU1 Gen eral-P urpose Output

O U6/B12 P9_31 MODE13

pr 2_pru1 _gpo11 PRU1 Gen eral-P urpose Output

O U5/A11 P9_29 MODE13

pr 2_pru1 _gpo12 PRU1 Gen eral-P urpose Output

O V5/B13 P9_30 MODE13

pr 2_pru1 _gpo13 PRU1 Gen eral-P urpose Output

O V4/A12 P9_26 MODE13

pr 2_pru1 _gpo14 PRU1 Gen eral-P urpose Output

O V3/E14 P9_42 MODE13

pr 2_pru1 _gpo15 PRU1 Gen eral-P urpose Output

O Y2/A13 P8_10 MODE13

pr 2_pru1 _gpo16 PRU1 Gen eral-P urpose Output

O W2/G14 P8_7 MODE13

pr 2_pru1 _gpo17 PRU1 Gen eral-P urpose Output

O E11 P8_27 MODE13

pr 2_pru1 _gpo18 PRU1 Gen eral-P urpose Output

O F11 P8_45 MODE13

pr 2_pru1 _gpo19 PRU1 Gen eral-P urpose Output

O G10 P8_46 MODE13

pr 2_pru1 _gpo20 PRU1 Gen eral-P urpose Output

O F10 P8_43 MODE13

p r2_pru 1_gpi0 PRU1 Gen eral-P urpose Input I V1/D17 P8_32 MODE12

p r2_pru 1_gpi1 PRU1 Gen eral-P urpose Input I U4/AA3 NA

p r2_pru 1_gpi2 PRU1 Gen eral-P urpose Input I U3/AB9 NA

p r2_pru 1_gpi3 PRU1 Gen eral-P urpose Input I V2/AB3 NA

p r2_pru 1_gpi4 PRU1 Gen eral-P urpose Input I Y1/AA4 NA p r2_pru 1_gpi5 PRU1 Gen eral-P urpose Input I W9/D18 P9_25 MODE12

p r2_pru 1_gpi6 PRU1 Gen eral-P urpose Input I V9/E17 P8_9 MODE12

p r2_pru 1_gpi7 PRU1 Gen eral-P urpose Input I V7/C14 P9_31 MODE12

p r2_pru 1_gpi8 PRU1 Gen eral-P urpose Input I U7/G12 P9_18 MODE12

p r2_pru 1_gpi9 PRU1 Gen eral-P urpose Input I V6/F12 P9_17 MODE12

continues on next page

### 34 Chapter 3. Design and specifications

Table 3.4 – continued from previous page

SIGNAL NAME DESCR IPTION TYPE PROC HEAD ER_PIN MODE HEAD ER_PIN MODE

pr 2_pru1 _gpi10 PRU1 Gen eral-P urpose Input I U6/B12 P9_31 MODE12

pr 2_pru1 _gpi11 PRU1 Gen eral-P urpose Input I U5/A11 P9_29 MODE12

pr 2_pru1 _gpi12 PRU1 Gen eral-P urpose Input I V5/B13 P9_30 MODE12

pr 2_pru1 _gpi13 PRU1 Gen eral-P urpose Input I V4/A12 P9_28 MODE12

pr 2_pru1 _gpi14 PRU1 Gen eral-P urpose Input I V3/E14 P9_42 MODE12

pr 2_pru1 _gpi15 PRU1 Gen eral-P urpose Input I Y2/A13 P8_10 MODE12

pr 2_pru1 _gpi16 PRU1 Gen eral-P urpose Input I W2/G14 P8_7 MODE12

pr 2_pru1 _gpi17 PRU1 Gen eral-P urpose Input I E11 P8_27 MODE12

pr 2_pru1 _gpi18 PRU1 Gen eral-P urpose Input I F11 P8_45 MODE12

pr 2_pru1 _gpi19 PRU1 Gen eral-P urpose Input I G10 P8_46 MODE12

pr 2_pru1 _gpi20 PRU1 Gen eral-P urpose Input I F10 P8_43 MODE12

pr2_e dc_lat ch0_in Latch Input 0 I F9 P8_42 MODE10

pr2_e dc_lat ch1_in Latch Input 1 I F8 P8_39 MODE10

pr2_e dc_syn c0_out SYNC0 Output

O E7 P8_40 MODE10

pr2_e dc_syn c1_out SYNC1 Output

O E8 P8_37 MODE10

pr2_e dio_la tch_in Latch Input I D9 P8_38 MODE10

pr2_ed io_sof Start Of Frame

O D7 P8_36 MODE10

pr2 _uart0 _cts_n UART C lear-T o-Send I D8 P8_34 MODE10

pr2 _uart0 _rts_n UART R eady-T o-Send

O A5 P8_35 MODE10

p r2_uar t0_rxd UART R eceive Data I C6 P8_33 MODE10

p r2_uar t0_txd UART Tr ansmit Data

O C8 P8_31 MODE10

pr2 _ecap0 _ecap_ capin_ apwm_o C apture Inp ut/PWM output IO C7 P8_32 MODE10

pr2_e dio_da ta_in0 Et hernet D igital Input I B7 P8_45 MODE10

pr2_e dio_da ta_in1 Et hernet D igital Input I B8 P9_11 MODE10

pr2_e dio_da ta_in2 Et hernet D igital Input I A7 P8_17 MODE10

pr2_e dio_da ta_in3 Et hernet D igital Input I A8 P8_27 MODE10

pr2_e dio_da ta_in4 Et hernet D igital Input I C9 P8_28 MODE10

pr2_e dio_da ta_in5 Et hernet D igital Input I A9 P8_29 MODE10

pr2_e dio_da ta_in6 Et hernet D igital Input I B9 P8_30 MODE10

pr2_e dio_da ta_in7 Et hernet D igital Input I A10 P8_46 MODE10

pr2_ed io_dat a_out0 Et hernet D igital Output

O B7 P8_45 MODE11

pr2_ed io_dat a_out1 Et hernet D igital Output

O B8 P9_11 MODE11

pr2_ed io_dat a_out2 Et hernet D igital Output

O A7 P8_17 MODE11

pr2_ed io_dat a_out3 Et hernet D igital Output

O A8 P8_27 MODE11

pr2_ed io_dat a_out4 Et hernet D igital Output

O C9 P8_28 MODE11

pr2_ed io_dat a_out5 Et hernet D igital Output

O A9 P8_29 MODE11

pr2_ed io_dat a_out6 Et hernet D igital Output

O B9 P8_30 MODE11

continues on next page

3.12. PRU-ICSS Resources and FAQ’s | 35

BeagleBone AI Table 3.4 ⁻ continued from previous page | SIGNAL NAME DESCR IPTION TYPE PROC HEAD ER_PIN MODE HEAD ER_PIN MODE | pr2_ed io_dat a_out7 Et hernet D igital Output

O A10 P8_46 MODE11

pr2_mi i1_col MII1 Col lision Detect I D18 P9_25 MODE11

pr2_mi i1_crs MII1 C arrier Sense I E17 P8_9 MODE11

pr 2_mdio _mdclk MDIO Clock

O C 14/AB3 P9_31 MODE11

p r2_mdi o_data MDIO Data IO D 14/AA4 P9_29 MODE11

p r2_mii 0_rxer MII0 R eceive Error I G12 P9_18 MODE11

pr2 _mii_m t0_clk MII0 Tr ansmit Clock I F12 P9_17 MODE11

p r2_mii 0_txen MII0 Tr ansmit Enable

O B12 P9_31 MODE11

p r2_mii 0_txd3 MII0 Tr ansmit Data

O A11 P9_29 MODE11

p r2_mii 0_txd2 MII0 Tr ansmit Data

O B13 P9_30 MODE11

p r2_mii 0_txd1 MII0 Tr ansmit Data

O A12 P9_28 MODE11

p r2_mii 0_txd0 MII0 Tr ansmit Data

O E14 P9_42 MODE11

pr2 _mii_m r0_clk MII0 R eceive Clock I A13 P8_10 MODE11

p r2_mii 0_rxdv MII0 Data Valid I G14 P8_7 MODE11

p r2_mii 0_rxd3 MII0 R eceive Data I F14 P8_8 MODE11

p r2_mii 0_rxd2 MII0 R eceive Data I A19 NA

p r2_mii 0_rxd1 MII0 R eceive Data I A18 NA

p r2_mii 0_rxd0 MII0 R eceive Data I C15 NA

pr2 _mii0_ rxlink MII0 R eceive Link I A16 NA

pr2_mi i0_crs MII0 C arrier Sense I B18 NA

pr2_mi i0_col MII0 Col lision Detect I F15 NA

p r2_mii 1_rxer MII1 R eceive Error I B19 P9_11 MODE11

pr2 _mii1_ rxlink MII1 R eceive Link I C17 P9_13 MODE11

pr2 _mii_m t1_clk MII1 Tr ansmit Clock I AC5 NA

p r2_mii 1_txen MII1 Tr ansmit Enable

O AB4 NA

p r2_mii 1_txd3 MII1 Tr ansmit Data

O AD4 P8_21 MODE11

p r2_mii 1_txd2 MII1 Tr ansmit Data

O AC4 P8_20 MODE11

p r2_mii 1_txd1 MII1 Tr ansmit Data

O AC7 P8_25 MODE11

p r2_mii 1_txd0 MII1 Tr ansmit Data

O AC6 P8_24 MODE11

pr2 _mii_m r1_clk MII1 R eceive Clock I AC9 P8_5 MODE11

p r2_mii 1_rxdv MII1 Data Valid I AC3 P8_6 MODE11

p r2_mii 1_rxd3 MII1 R eceive Data I AC8 P8_23 MODE11

p r2_mii 1_rxd2 MII1 R eceive Data I AD6 P8_22 MODE11

p r2_mii 1_rxd1 MII1 R eceive Data I AB8 P8_3 MODE11

p r2_mii 1_rxd0 MII1 R eceive Data I AB5 P8_4 MODE11 end end end end end end end end

### 36 Chapter 3. Design and specifications

## 3.13 User LEDs

There are 5 User Programmable LEDs on BeagleBone® AI. These are connected to GPIO pins on the processor.

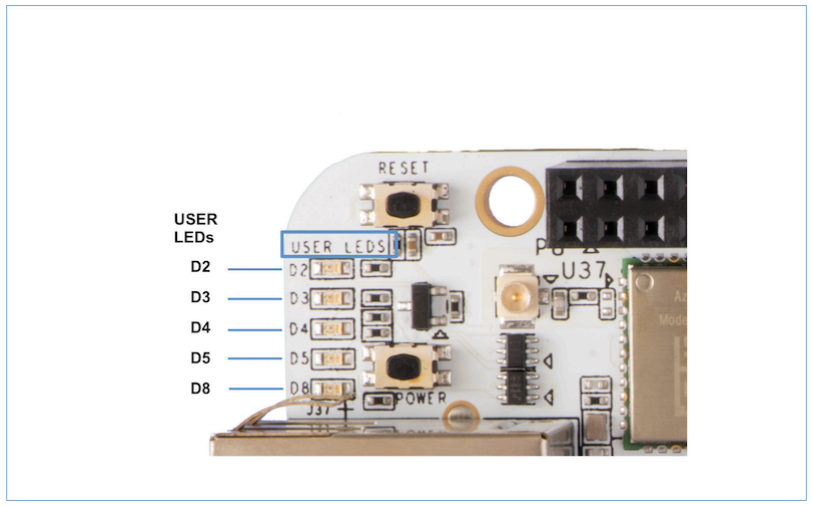
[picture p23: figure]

The table shows the signals used to control the LEDs from the processor. Each LED is user programmable. However, there is a Default Functions assigned in the device tree for BeagleBone® AI:

LED | GPIO SIGNAL | DEFAULT FUNCTION
D2 | GPIO3_17 | Heartbeat When Linux is Running
D3 | GPIO5_5 | microSD Activity
D4 | GPIO3_15 | CPU Activity
D5 | GPIO3_14 | eMMC Activity
D8 | GPIO3_7 | WiFi/Bluetooth Activity
3.13. User LEDs | 37

### 38 Chapter 3. Design and specifications

# Chapter 4

# Expansion

## 4.1 Expansion Connectors

The expansion interface on the board is comprised of two 46 pin connectors, the P8 and P9 Headers. All signals on the expansion headers are 3.3V unless otherwise indicated.

Note: Do not connect 5V logic level signals to these pins or the board will be damaged.

Note: DO NOT APPLY VOLTAGE TO ANY I/O PIN WHEN POWER IS NOT SUPPLIED TO THE BOARD. IT WILL DAMAGE THE PROCESSOR AND VOID THE WARRANTY.

NO PINS ARE TO BE DRIVEN UNTIL AFTER THE SYS_RESET LINE GOES HIGH.

Figure ? shows the location of the expansion connectors.

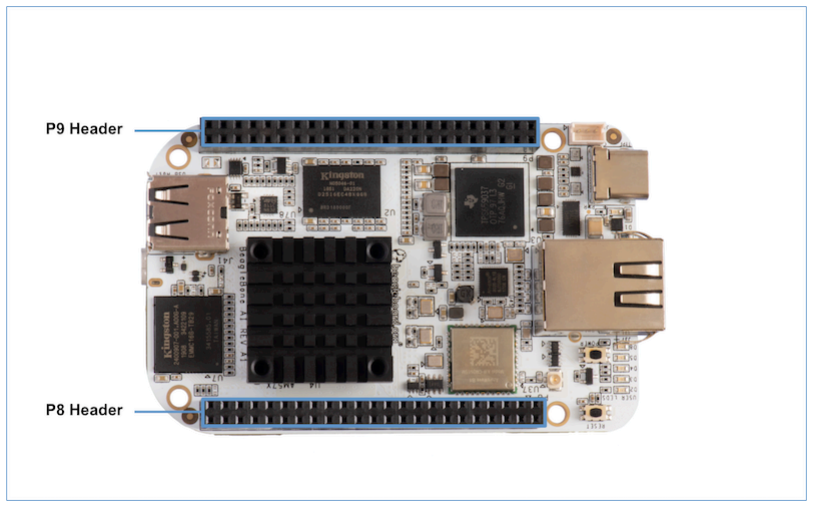
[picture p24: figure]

The location and spacing of the expansion headers are the same as on BeagleBone Black.

39

### 4.1.1 Connector P8

The following tables show the pinout of the P8 expansion header. The SW is responsible for setting the default function of each pin. Refer to the processor documentation for more information on these pins and detailed descriptions of all of the pins listed. In some cases there may not be enough signals to complete a group of signals that may be required to implement a total interface.

The column heading is the pin number on the expansion header.

The GPIO row is the expected gpio identifier number in the Linux kernel.

The BALL row is the pin number on the processor.

The REG row is the offset of the control register for the processor pin.

The MODE # rows are the mode setting for each pin. Setting each mode to align with the mode column will give that function on that pin.

If included, the 2nd BALL row is the pin number on the processor for a second processor pin connected to the same pin on the expansion header. Similarly, all row headings starting with 2nd refer to data for this second processor pin.

Note: DO NOT APPLY VOLTAGE TO ANY I/O PIN WHEN POWER IS NOT SUPPLIED TO THE BOARD. IT WILL DAMAGE THE PROCESSOR AND VOID THE WARRANTY.

NO PINS ARE TO BE DRIVEN UNTIL AFTER THE SYS_RESET LINE GOES HIGH.

Table 4.1: P8.01-P8.02

P8.01 | P8.02
GND | GND

Table 4.2: P8.03-P8.05

P8.03 | P8.04 | P8.05
GPIO | 24 | 25 | 193
BALL | AB8 | AB5 | AC9
REG | 0x179C | 0x17A0 | 0x178C
MODE 0 | mmc3_dat6 | mmc3_dat7 | mmc3_dat2
1 | spi4_d0 | spi4_cs0 | spi3_cs0
2 | uart10_ctsn | uart10_rtsn | uart5_ctsn
3
4 | vin2b_de1 | vin2b_clk1 | vin2b_d3
5
6
7
8
9 | vin5a_hsync0 | vin5a_vsync0 | vin5a_d3
10 | ehrpwm3_tripzone_input | eCAP3_in_PWM3_out | eQEP3_index
11 | pr2_mii1_rxd1 | pr2_mii1_rxd0 | pr2_mii_mr1_clk
12 | pr2_pru0_gpi10 | pr2_pru0_gpi11 | pr2_pru0_gpi6
13 | pr2_pru0_gpo10 | pr2_pru0_gpo11 | pr2_pru0_gpo6
14 | gpio1_24 | gpio1_25 | gpio7_1
15 | Driver off | Driver off | Driver off

### 40 Chapter 4. Expansion

Table 4.3: P8.06-P8.09

P8.06 | P8.07 | P8.08 | P8.09
GPIO | 194 | 165 | 166 | 178
BALL | AC3 | G14 | F14 | E17
REG | 0x1790 | 0x16EC | 0x16F0 | 0x1698
MODE0 | mmc3_dat3 | mcasp1_axr14 | mcasp1_axr15 | xref_clk1
1 | spi3_cs1 | mcasp7_aclkx | mcasp7_fsx | mcasp2_axr9
2 | uart5_rtsn | mcasp7_aclkr | mcasp7_fsr | mcasp1_axr5
3 mcasp2_ahclkx
4 | vin2b_d2 | | | mcasp6_ahclkx
5
6
7 | | vin6a_d9 | vin6a_d8 | vin6a_clk0
8
9 vin5a_d2
10 | eQEP3_strobe | timer11 | timer12 | timer14
11 | pr2_mii1_rxdv | pr2_mii0_rxdv | pr2_mii0_rxd3 | pr2_mii1_crs
12 | pr2_pru0_gpi7 | pr2_pru1_gpi16 | pr2_pru0_gpi20 | pr2_pru1_gpi6
13 | pr2_pru0_gpo7 | pr2_pru1_gpo16 | pr2_pru0_gpo20 | pr2_pru1_gpo6
14 | gpio7_2 | gpio6_5 | gpio6_6 | gpio6_18
15 | Driver off | Driver off | Driver off | Driver off

Table 4.4: P8.10-P8.13

P8.10 | P8.11 | P8.12 | P8.13
GPIO | 164 | 75 | 74 | 107
BALL | A13 | AH4 | AG6 | D3
REG | 0x16E8 | 0x1510 | 0x150C | 0x1590
MODE 0 | mcasp1_axr13 | vin1a_d7 | vin1a_d6 | vin2a_d10
1 mcasp7_axr1
2
3 | | vout3_d0 | vout3_d1 | mdio_mclk
4 | | vout3_d16 | vout3_d17 | vout2_d13
5
6
7 vin6a_d10
8
9 kbd_col7
10 | timer10 | eQEP2B_in | eQEP2A_in | ehrpwm2B
11 | pr2_mii_mr0_clk | | | pr1_mdio_mdclk
12 | pr2_pru1_gpi15 | pr1_pru0_gpi4 | pr1_pru0_gpi3 | pr1_pru1_gpi7
13 | pr2_pru1_gpo15 | pr1_pru0_gpo4 | pr1_pru0_gpo3 | pr1_pru1_gpo7
14 | gpio6_4 | gpio3_11 | gpio3_10 | gpio4_11
15 | Driver off | Driver off | Driver off | Driver off

Table 4.5: P8.14-P8.16
P8.14 | P8.15 | P8.16
GPIO | 109 | 99 | 125
BALL | D5 | D1 | B4
REG | 0x1598 | 0x1570 | 0x15BC
MODE 0 | vin2a_d12 | vin2a_d2 | vin2a_d21
1
2 vin2b_d2
3 | rgmii1_txc | | rgmii1_rxd2
4 | vout2_d11 | vout2_d21 | vout2_d2
5 | | emu12 | vin3a_fld0
6 vin3a_d13
7
8 | mii1_rxclk | uart10_rxd | mii1_col
9 | kbd_col8 | kbd_row6

### continues on next page

4.1. Expansion Connectors | 41

### Table 4.5 – continued from previous page

P8.14 | P8.15 | P8.16
10 | eCAP2_in_PWM2_out | eCAP1_in_PWM1_out
11 | pr1_mii1_txd1 | pr1_ecap0_ecap_capin_apwm_o | pr1_mii1_rxlink
12 | pr1_pru1_gpi9 | pr1_edio_data_in7 | pr1_pru1_gpi18
13 | pr1_pru1_gpo9 | pr1_edio_data_out7 | pr1_pru1_gpo18
14 | gpio4_13 | gpio4_3 | gpio4_29
15 | Driver off | Driver off | Driver off
2nd BALL | | A3
2nd REG | | 0x15B4
2nd MODE 0 | | vin2a_d19
2nd 1
2nd 2 | | vin2b_d4
2nd 3 | | rgmii1_rxctl
2nd 4 | | vout2_d4
2nd 5
2nd 6 | | vin3a_d11
2nd 7
2nd 8 | | mii1_txer
2nd 9
2nd 10 | | ehrpwm3_tripzone_input
2nd 11 | | pr1_mii1_rxd0
2nd 12 | | pr1_pru1_gpi16
2nd 13 | | pr1_pru1_gpo16
2nd 14 | | gpio4_27
2nd 15 | | Driver off

Table 4.6: P8.17-P8.19

P8.17 | P8.18 | P8.19
GPIO | 242 | 105 | 106
BALL | A7 | F5 | E6
REG | 0x1624 | 0x1588 | 0x158C
MODE 0 | vout1_d18 | vin2a_d8 | vin2a_d9
1
2 emu4
3 vin4a_d2
4 | vin3a_d2 | vout2_d15 | vout2_d14
5 | obs11 | emu18 | emu19
6 obs27
7
8 | | mii1_rxd3 | mii1_rxd0
9 | | kbd_col5 | kbd_col6
10 | pr2_edio_data_in2 | eQEP2_strobe | ehrpwm2A
11 | pr2_edio_data_out2 | pr1_mii1_txd3 | pr1_mii1_txd2
12 | pr2_pru0_gpi15 | pr1_pru1_gpi5 | pr1_pru1_gpi6
13 | pr2_pru0_gpo15 | pr1_pru1_gpo5 | pr1_pru1_gpo6
14 | gpio8_18 | gpio4_9 | gpio4_10
15 | Driver off | Driver off | Driver off

### 42 Chapter 4. Expansion

Table 4.7: P8.20-P8.22

P8.20 | P8.21 | P8.22
GPIO | 190 | 189 | 23
BALL | AC4 | AD4 | AD6
REG | 0x1780 | 0x177C | 0x1798
MODE 0 | mmc3_cmd | mmc3_clk | mmc3_dat5
1 | spi3_sclk | | spi4_d1
2 uart10_txd
3
4 | vin2b_d6 | vin2b_d7 | vin2b_d0
5
6
7
8
9 | vin5a_d6 | vin5a_d7 | vin5a_d0
10 | eCAP2_in_PWM2_out | ehrpwm2_tripzone_input | ehrpwm3B
11 | pr2_mii1_txd2 | pr2_mii1_txd3 | pr2_mii1_rxd2
12 | pr2_pru0_gpi3 | pr2_pru0_gpi2 | pr2_pru0_gpi9
13 | pr2_pru0_gpo3 | pr2_pru0_gpo2 | pr2_pru0_gpo9
14 | gpio6_30 | gpio6_29 | gpio1_23
15 | Driver off | Driver off | Driver off

Table 4.8: P8.23-P8.26

P8.23 | P8.24 | P8.25 | P8.26
GPIO | 22 | 192 | 191 | 124
BALL | AC8 | AC6 | AC7 | B3
REG | 0x1794 | 0x1788 | 0x1784 | 0x15B8
MODE 0 | mmc3_dat4 | mmc3_dat1 | mmc3_dat0 | vin2a_d20
1 | spi4_sclk | spi3_d0 | spi3_d1
2 | uart10_rxd | uart5_txd | uart5_rxd | vin2b_d3
3 rgmii1_rxd3
4 | vin2b_d1 | vin2b_d4 | vin2b_d5 | vout2_d3
5 vin3a_de0
6 vin3a_d12
7
8 mii1_rxer
9 | vin5a_d1 | vin5a_d4 | vin5a_d5
10 | ehrpwm3A | eQEP3B_in | eQEP3A_in | eCAP3_in_PWM3_out
11 | pr2_mii1_rxd3 | pr2_mii1_txd0 | pr2_mii1_txd1 | pr1_mii1_rxer
12 | pr2_pru0_gpi8 | pr2_pru0_gpi5 | pr2_pru0_gpi4 | pr1_pru1_gpi17
13 | pr2_pru0_gpo8 | pr2_pru0_gpo5 | pr2_pru0_gpo4 | pr1_pru1_gpo17
14 | gpio1_22 | gpio7_0 | gpio6_31 | gpio4_28
15 | Driver off | Driver off | Driver off | Driver off

Table 4.9: P8.27-P8.29
P8.27 | P8.28 | P8.29
GPIO | 119 | 115 | 118
BALL | E11 | D11 | C11
REG | 0x15D8 | 0x15C8 | 0x15D4
MODE 0 | vout1_vsync | vout1_clk | vout1_hsync
1
2
3 | vin4a_vsync0 | vin4a_fld0 | vin4a_hsync0
4 | vin3a_vsync0 | vin3a_fld0 | vin3a_hsync0
5
6
7
8 | spi3_sclk | spi3_cs0 | spi3_d0
9

### continues on next page

4.1. Expansion Connectors | 43

### Table 4.9 – continued from previous page

P8.27 | P8.28 | P8.29

10
11
12 pr2_pru1_gpi17
13 pr2_pru1_gpo17
14 | gpio4_23 | gpio4_19 | gpio4_22
15 | Driver off | Driver off | Driver off
2nd BALL | A8 | C9 | A9
2nd REG | 0x1628 | 0x162C | 0x1630
2nd MODE0 | vout1_d19 | vout1_d20 | vout1_d21
2nd 1
2nd 2 | emu15 | emu16 | emu17
2nd 3 | vin4a_d3 | vin4a_d4 | vin4a_d5
2nd 4 | vin3a_d3 | vin3a_d4 | vin3a_d5
2nd 5 | obs12 | obs13 | obs14
2nd 6 | obs28 | obs29 | obs30
2nd 7
2nd 8
2nd 9
2nd 10 | pr2_edio_data_in3 | pr2_edio_data_in4 | pr2_edio_data_in5
2nd 11 | pr2_edio_data_out3 | pr2_edio_data_out4 | pr2_edio_data_out5
2nd 12 | pr2_pru0_gpi16 | pr2_pru0_gpi17 | pr2_pru0_gpi18
2nd 13 | pr2_pru0_gpo16 | pr2_pru0_gpo17 | pr2_pru0_gpo18
2nd 14 | gpio8_19 | gpio8_20 | gpio8_21
2nd 15 | Driver off | Driver off | Driver off

Table 4.10: P8.30-P8.32
P8.30 | P8.31 | P8.32
GPIO | 116 | 238 | 239
BALL | B10 | C8 | C7
REG | 0x15CC | 0x1614 | 0x1618
MODE 0 | vout1_de | vout1_d14 | vout1_d15
1
2 | | emu13 | emu14
3 | vin4a_de0 | vin4a_d14 | vin4a_d15
4 | vin3a_de0 | vin3a_d14 | vin3a_d15
5 | | obs9 | obs10
6 | | obs25 | obs26
7
8 spi3_d1
9
10 | | pr2_uart0_txd | pr2_ecap0_ecap_capin_apwm_o
11
12 | | pr2_pru0_gpi11 | pr2_pru0_gpi12
13 | | pr2_pru0_gpo11 | pr2_pru0_gpo12
14 | gpio4_20 | gpio8_14 | gpio8_15
15 | Driver off | Driver off | Driver off
2nd BALL | B9 | G16 | D17
2nd REG | 0x1634 | 0x173C | 0x1740
2nd MODE 0 | vout1_d22 | mcasp4_axr0 | mcasp4_axr1
2nd 1
2nd 2 | emu18 | spi3_d0 | spi3_cs0
2nd 3 | vin4a_d6 | uart8_ctsn | uart8_rtsn

### continues on next page

### 44 Chapter 4. Expansion

### Table 4.10 – continued from previous page

P8.30 | P8.31 | P8.32
2nd 4 | vin3a_d6 | uart4_rxd | uart4_txd
2nd 5 | obs15
2nd 6 | obs31 | vout2_d18 | vout2_d19
2nd 7
2nd 8 | | vin4a_d18 | vin4a_d19
2nd 9 | | vin5a_d13 | vin5a_d12
2nd 10 | pr2_edio_data_in6
2nd 11 | pr2_edio_data_out6
2nd 12 | pr2_pru0_gpi19 | | pr2_pru1_gpi0
2nd 13 | pr2_pru0_gpo19 | | pr2_pru1_gpo0
2nd 14 | gpio8_22
2nd 15 | Driver off | Driver off | Driver off

Table 4.11: P8.33-P8.35
P8.33 | P8.34 | P8.35
GPIO | 237 | 235 | 236
BALL | C6 | D8 | A5
REG | 0x1610 | 0x1608 | 0x160C
MODE 0 | vout1_d13 | vout1_d11 | vout1_d12
1
2 | emu12 | emu10 | emu11
3 | vin4a_d13 | vin4a_d11 | vin4a_d12
4 | vin3a_d13 | vin3a_d11 | vin3a_d12
5 | obs8 | obs6 | obs7
6 | obs24 | obs22 | obs23
7 obs_dmarq2
8
9
10 | pr2_uart0_rxd | pr2_uart0_cts_n | pr2_uart0_rts_n
11
12 | pr2_pru0_gpi10 | pr2_pru0_gpi8 | pr2_pru0_gpi9
13 | pr2_pru0_gpo10 | pr2_pru0_gpo8 | pr2_pru0_gpo9
14 | gpio8_13 | gpio8_11 | gpio8_12
15 | Driver off | Driver off | Driver off
2nd BALL | AF9 | G6 | AD9
2nd REG | 0x14E8 | 0x1564 | 0x14E4
2nd MODE0 | vin1a_fld0 | vin2a_vsync0 | vin1a_de0
2nd 1 | vin1b_vsync1 | | vin1b_hsync1
2nd 2
2nd 3 | | vin2b_vsync1 | vout3_d17
2nd 4 | vout3_clk | vout2_vsync | vout3_de
2nd 5 | uart7_txd | emu9 | uart7_rxd
2nd 6
2nd 7 | timer15 | uart9_txd | timer16
2nd 8 | spi3_d1 | spi4_d1 | spi3_sclk
2nd 9 | kbd_row1 | kbd_row3 | kbd_row0
2nd 10 | eQEP1B_in | ehrpwm1A | eQEP1A_in
2nd 11 | | pr1_uart0_rts_n
2nd 12 | | pr1_edio_data_in4
2nd 13 | | pr1_edio_data_out4
2nd 14 | gpio3_1 | gpio4_0 | gpio3_0
2nd 15 | Driver off | Driver off | Driver off
4.1. Expansion Connectors | 45

Table 4.12: P8.36-P8.38
P8.36 | P8.37 | P8.38
GPIO | 234 | 232 | 233
BALL | D7 | E8 | D9
REG | 0x1604 | 0x15FC | 0x1600
MODE 0 | vout1_d10 | vout1_d8 | vout1_d9
1
2 | emu3 | uart6_rxd | uart6_txd
3 | vin4a_d10 | vin4a_d8 | vin4a_d9
4 | vin3a_d10 | vin3a_d8 | vin3a_d9
5 obs5
6 obs21
7 obs_irq2
8
9
10 | pr2_edio_sof | pr2_edc_sync1_out | pr2_edio_latch_in
11
12 | pr2_pru0_gpi7 | pr2_pru0_gpi5 | pr2_pru0_gpi6
13 | pr2_pru0_gpo7 | pr2_pru0_gpo5 | pr2_pru0_gpo6
14 | gpio8_10 | gpio8_8 | gpio8_9
15 | Driver off | Driver off | Driver off
2nd BALL | F2 | A21 | C18
2nd REG | 0x1568 | 0x1738 | 0x1734
2nd MODE 0 | vin2a_d0 | mcasp4_fsx | mcasp4_aclkx
2nd 1 | | mcasp4_fsr | mcasp4_aclkr
2nd 2 | | spi3_d1 | spi3_sclk
2nd 3 | | uart8_txd | uart8_rxd
2nd 4 | vout2_d23 | i2c4_scl | i2c4_sda
2nd 5 | emu10
2nd 6 | | vout2_d17 | vout2_d16
2nd 7 | uart9_ctsn
2nd 8 | spi4_d0 | vin4a_d17 | vin4a_d16
2nd 9 | kbd_row4 | vin5a_d14 | vin5a_d15
2nd 10 | ehrpwm1B
2nd 11 | pr1_uart0_rxd
2nd 12 | pr1_edio_data_in5
2nd 13 | pr1_edio_data_out5
2nd 14 | gpio4_1
2nd 15 | Driver off | Driver off | Driver off

### 46 Chapter 4. Expansion

Table 4.13: P8.39-P8.41

P8.39 | P8.40 | P8.41
GPIO | 230 | 231 | 228
BALL | F8 | E7 | E9
REG | 0x15F4 | 0x15F8 | 0x15EC
MODE 0 | vout1_d6 | vout1_d7 | vout1_d4
1
2 | emu8 | emu9 | emu6
3 | vin4a_d22 | vin4a_d23 | vin4a_d20
4 | vin3a_d22 | vin3a_d23 | vin3a_d20
5 | obs4 | | obs2
6 | obs20 | | obs18
7
8
9
10 | pr2_edc_latch1_in | pr2_edc_sync0_out | pr1_ecap0_ecap_capin_apwm_o
11
12 | pr2_pru0_gpi3 | pr2_pru0_gpi4 | pr2_pru0_gpi1
13 | pr2_pru0_gpo3 | pr2_pru0_gpo4 | pr2_pru0_gpo1
14 | gpio8_6 | gpio8_7 | gpio8_4
15 | Driver off | Driver off | Driver off

Table 4.14: P8.42-P8.44

P8.42 | P8.43 | P8.44
GPIO | 229 | 226 | 227
BALL | F9 | F10 | G11
REG | 0x15F0 | 0x15E4 | 0x15E8
MODE 0 | vout1_d5 | vout1_d2 | vout1_d3
1
2 | emu7 | emu2 | emu5
3 | vin4a_d21 | vin4a_d18 | vin4a_d19
4 | vin3a_d21 | vin3a_d18 | vin3a_d19
5 | obs3 | obs0 | obs1
6 | obs19 | obs16 | obs17
7 | | obs_irq1 | obs_dmarq1
8
9
10 | pr2_edc_latch0_in | pr1_uart0_rxd | pr1_uart0_txd
11
12 | pr2_pru0_gpi2 | pr2_pru1_gpi20 | pr2_pru0_gpi0
13 | pr2_pru0_gpo2 | pr2_pru1_gpo20 | pr2_pru0_gpo0
14 | gpio8_5 | gpio8_2 | gpio8_3
15 | Driver off | Driver off | Driver off

Table 4.15: P8.45-P8.46
P8.45 | P8.46
GPIO | 224 | 225
BALL | F11 | G10
REG | 0x15DC | 0x15E0
MODE 0 | vout1_d0 | vout1_d1
1
2 | uart5_rxd | uart5_txd
3 | vin4a_d16 | vin4a_d17
4 | vin3a_d16 | vin3a_d17
5
6
7
8 spi3_cs2
9

### continues on next page

4.1. Expansion Connectors | 47

### Table 4.15 – continued from previous page

P8.45 | P8.46
10 | pr1_uart0_cts_n | pr1_uart0_rts_n
11
12 | pr2_pru1_gpi18 | pr2_pru1_gpi19
13 | pr2_pru1_gpo18 | pr2_pru1_gpo19
14 | gpio8_0 | gpio8_1
15 | Driver off | Driver off
2nd BALL | B7 | A10
2nd REG | 0x161C | 0x1638
2nd MODE 0 | vout1_d16 | vout1_d23
2nd 1
2nd 2 | uart7_rxd | emu19
2nd 3 | vin4a_d0 | vin4a_d7
2nd 4 | vin3a_d0 | vin3a_d7
2nd 5
2nd 6
2nd 7
2nd 8 | | spi3_cs3
2nd 9
2nd 10 | pr2_edio_data_in0 | pr2_edio_data_in7
2nd 11 | pr2_edio_data_out0 | pr2_edio_data_out7
2nd 12 | pr2_pru0_gpi13 | pr2_pru0_gpi20
2nd 13 | pr2_pru0_gpo13 | pr2_pru0_gpo20
2nd 14 | gpio8_16 | gpio8_23
2nd 15 | Driver off | Driver off

### 4.1.2 Connector P9

The following tables show the pinout of the P9 expansion header. The SW is responsible for setting the default function of each pin. Refer to the processor documentation for more information on these pins and detailed descriptions of all of the pins listed. In some cases there may not be enough signals to complete a group of signals that may be required to implement a total interface.

The column heading is the pin number on the expansion header.

The GPIO row is the expected gpio identifier number in the Linux kernel.

The BALL row is the pin number on the processor.

The REG row is the offset of the control register for the processor pin.

The MODE # rows are the mode setting for each pin. Setting each mode to align with the mode column will give that function on that pin.

If included, the 2nd BALL row is the pin number on the processor for a second processor pin connected to the same pin on the expansion header. Similarly, all row headings starting with 2nd refer to data for this second processor pin.

NOTES:

DO NOT APPLY VOLTAGE TO ANY I/O PIN WHEN POWER IS NOT SUPPLIED TO THE BOARD. IT WILL DAMAGE THE PROCESSOR AND VOID THE WARRANTY.

NO PINS ARE TO BE DRIVEN UNTIL AFTER THE SYS_RESET LINE GOES HIGH.

In the table are the following notations:

PWR_BUT is a 5V level as pulled up internally by the TPS6590379. It is activated by pulling the signal to GND.

### 48 Chapter 4. Expansion

Table 4.16: P9.01-P9.05

P9.01 | P9.02 | P9.03 | P9.04 | P9.05
GND | GND | VOUT_3V3 | VOUT_3V3 | VIN

Table 4.17: P9.06-P9.10

P9.06 | P9.07 | P9.08 | P9.09 | P9.10
VIN | VOUT_SYS | VOUT_SYS | RESET# | RESET#

Table 4.18: P9.11-P9.13
P9.11 | P9.12 | P9.13
GPIO | 241 | 128 | 172
BALL | B19 | B14 | C17
REG | 0x172C | 0x16AC | 0x1730
MODE 0 | mcasp3_axr0 | mcasp1_aclkr | mcasp3_axr1
1 mcasp7_axr2
2 | mcasp2_axr14 | | mcasp2_axr15
3 | uart7_ctsn | | uart7_rtsn
4 | uart5_rxd | | uart5_txd
5
6 vout2_d0
7 | vin6a_d1 | | vin6a_d0
8 vin4a_d0
9 vin5a_fld0
10 i2c4_sda
11 | pr2_mii1_rxer | | pr2_mii1_rxlink
12 | pr2_pru0_gpi14 | | pr2_pru0_gpi15
13 | pr2_pru0_gpo14 | | pr2_pru0_gpo15
14 gpio5_0
15 | Driver off | Driver off | Driver off
2nd BALL | B8 | | AB10**
2nd REG | 0x1620 | | 0x1680
2nd MODE 0 | vout1_d17 | | usb1_drvvbus
2nd 1
2nd 2 | uart7_txd
2nd 3 | vin4a_d1
2nd 4 | vin3a_d1
2nd 5
2nd 6
2nd 7 | | | timer16
2nd 8
2nd 9
2nd 10 | pr2_edio_data_in1
2nd 11 | pr2_edio_data_out1
2nd 12 | pr2_pru0_gpi14
2nd 13 | pr2_pru0_gpo14
2nd 14 | gpio8_17 | | gpio6_12
2nd 15 | Driver off | | Driver off
4.1. Expansion Connectors | 49

Table 4.19: P9.14-P9.16

P9.14 | P9.15 | P9.16
GPIO | 121 | 76 | 122
BALL | D6 | AG4 | C5
REG | 0x15AC | 0x1514 | 0x15B0
MODE 0 | vin2a_d17 | vin1a_d8 | vin2a_d18
1 vin1b_d7
2 | vin2b_d6 | | vin2b_d5
3 | rgmii1_txd0 | | rgmii1_rxc
4 | vout2_d6 | vout3_d15 | vout2_d5
5
6 | vin3a_d9 | | vin3a_d10
7
8 | mii1_txd2 | | mii1_txd3
9 kbd_row2
10 | ehrpwm3A | eQEP2_index | ehrpwm3B
11 | pr1_mii1_rxd2 | | pr1_mii1_rxd1
12 | pr1_pru1_gpi14 | pr1_pru0_gpi5 | pr1_pru1_gpi15
13 | pr1_pru1_gpo14 | pr1_pru0_gpo5 | pr1_pru1_gpo15
14 | gpio4_25 | gpio3_12 | gpio4_26
15 | Driver off | Driver off | Driver off

Table 4.20: P9.17-P9.19
P9.17 | P9.18 | P9.19
GPIO | 209 | 208 | 195
BALL | B24 | G17 | R6
REG | 0x17CC | 0x17C8 | 0x1440
MODE 0 | spi2_cs0 | spi2_d0 | gpmc_a0
1 | uart3_rtsn | uart3_ctsn
2 | uart5_txd | uart5_rxd | vin3a_d16
3 vout3_d16
4 vin4a_d0
5
6 vin4b_d0
7 i2c4_scl
8 uart5_rxd
9
10
11
12
13
14 | gpio7_17 | gpio7_16 | gpio7_3
15 | Driver off | Driver off | Driver off
2nd BALL | F12 | G12 | F4
2nd REG | 0x16B8 | 0x16B4 | 0x157C
2nd MODE 0 | mcasp1_axr1 | mcasp1_axr0 | vin2a_d5
2nd 1
2nd 2
2nd 3 | uart6_txd | uart6_rxd
2nd 4 | | | vout2_d18
2nd 5 | | | emu15
2nd 6
2nd 7 | vin6a_hsync0 | vin6a_vsync0
2nd 8 | | | uart10_rtsn
2nd 9 | | | kbd_col2
2nd 10 | i2c5_scl | i2c5_sda | eQEP2A_in
2nd 11 | pr2_mii_mt0_clk | pr2_mii0_rxer | pr1_edio_sof

### continues on next page

### 50 Chapter 4. Expansion
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

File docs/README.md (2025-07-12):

# Hexapod Robot Documentation

This directory contains comprehensive documentation for the reinforcement learning-enabled hexapod robot project. The documentation covers hardware specifications, software architecture, quickstart guides, and detailed diagrams.

## Documentation Overview

| File | Description |
|---|---|
| [architecture.md](architecture.md) | Detailed software architecture, design patterns, and component interactions |
| [hardware.md](hardware.md) | Hardware specifications, wiring diagrams, and component assembly instructions |
| [quickstart.md](quickstart.md) | Getting started guide for new users to quickly set up and operate the hexapod |

## Diagram Documentation

The `diagrams/` directory contains PlantUML source files that generate various system diagrams:

| Diagram | Description |
|---|---|
| [class.puml](diagrams/src/class.puml) | Class diagrams showing software component relationships |
| [component.puml](diagrams/src/component.puml) | Component diagrams illustrating system modules |
| [sequence.puml](diagrams/src/sequence.puml) | Sequence diagrams for key interactions and processes |
| [state.puml](diagrams/src/state.puml) | State machine diagrams for robot control states |
| [deployment.puml](diagrams/src/deployment.puml) | Deployment diagrams showing hardware/software distribution |
| [building.puml](diagrams/src/building.puml) | Diagrams explaining the build and compilation process |

## Generating Diagrams

The PlantUML diagrams can be generated into visual formats using the following commands:

```bash
# Install PlantUML (Debian/Ubuntu)
sudo apt install plantuml

# Generate all diagrams
./scripts/build.sh -l
```

Generated diagrams will be saved in the docs/diagrams/image/ directory as their source files with `.png` extensions.

## Viewing Documentation

For the best viewing experience, use a Markdown viewer or editor that supports:

- Tables
- Code highlighting
- Image embedding

You can view the documentation directly on GitHub or use tools like VSCode with the Markdown Preview extension.

## Documentation Structure

```t
docs/
├── README.md               # This file
├── architecture.md         # Software architecture details
├── hardware.md             # Hardware specifications and setup
├── quickstart.md           # Getting started guide
└── diagrams/               # System diagrams
    └── src/                # PlantUML source files
        ├── class.puml
        ├── component.puml
        ├── sequence.puml
        ├── state.puml
        ├── deployment.puml
        └── building.puml
```

## Contributing to Documentation
When contributing to the documentation, please follow these guidelines:
1. Use clear, concise language
2. Include code examples where appropriate
3. Add diagrams for complex concepts
4. Ensure code snippets are syntax-highlighted
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

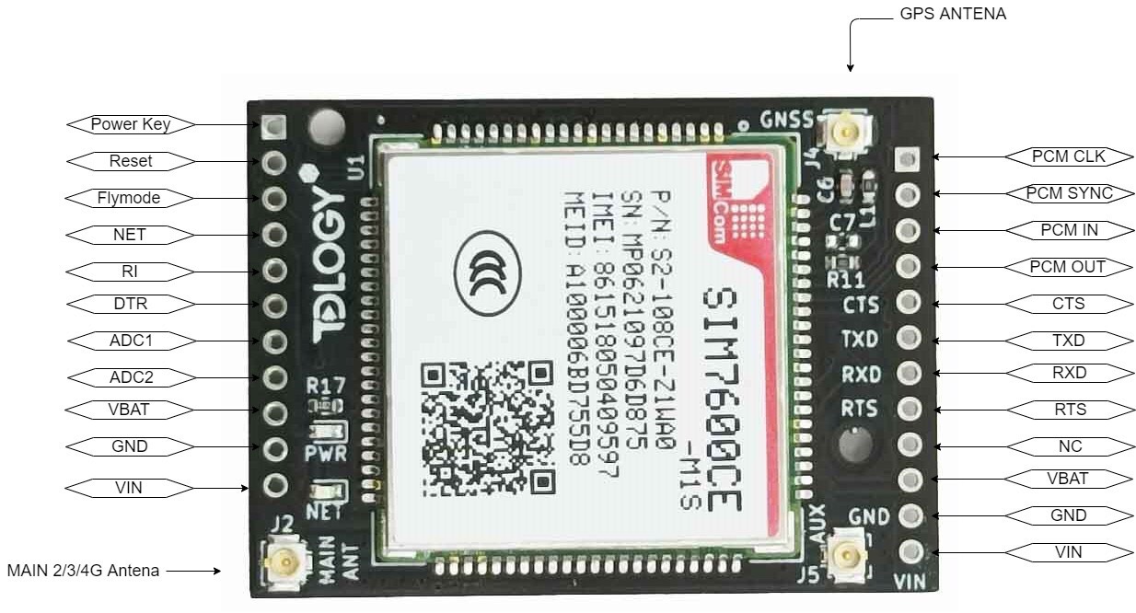
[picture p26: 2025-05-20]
docs/sim7600ceM1S/pinout.jpg

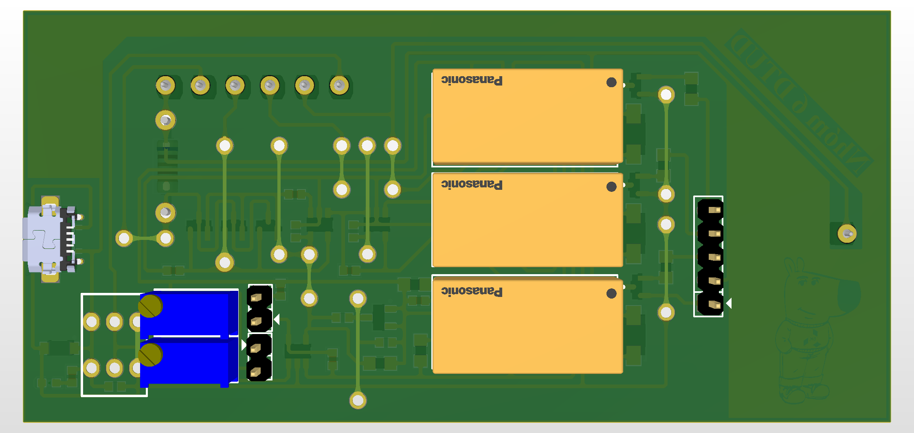
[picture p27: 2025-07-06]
hardware/References/IR_Distance_Sensor/PCB_Project/PCBBack.png

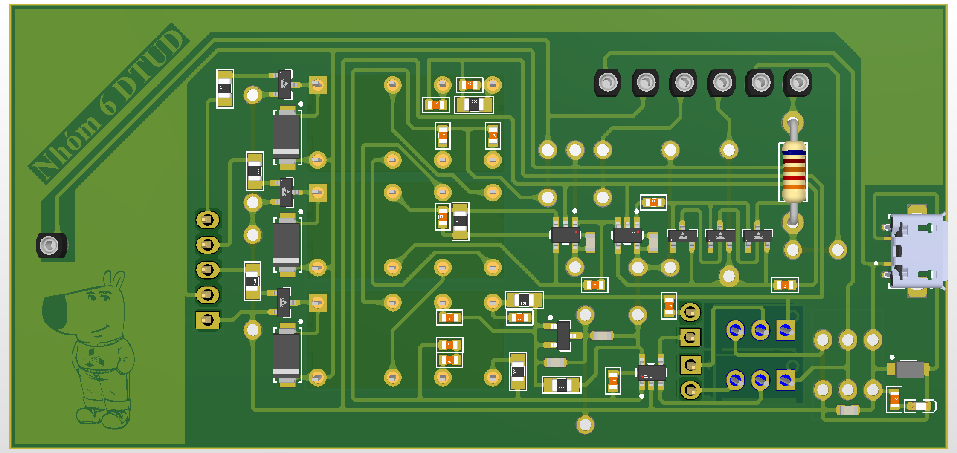
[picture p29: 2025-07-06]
hardware/References/IR_Distance_Sensor/PCB_Project/PCB1.png

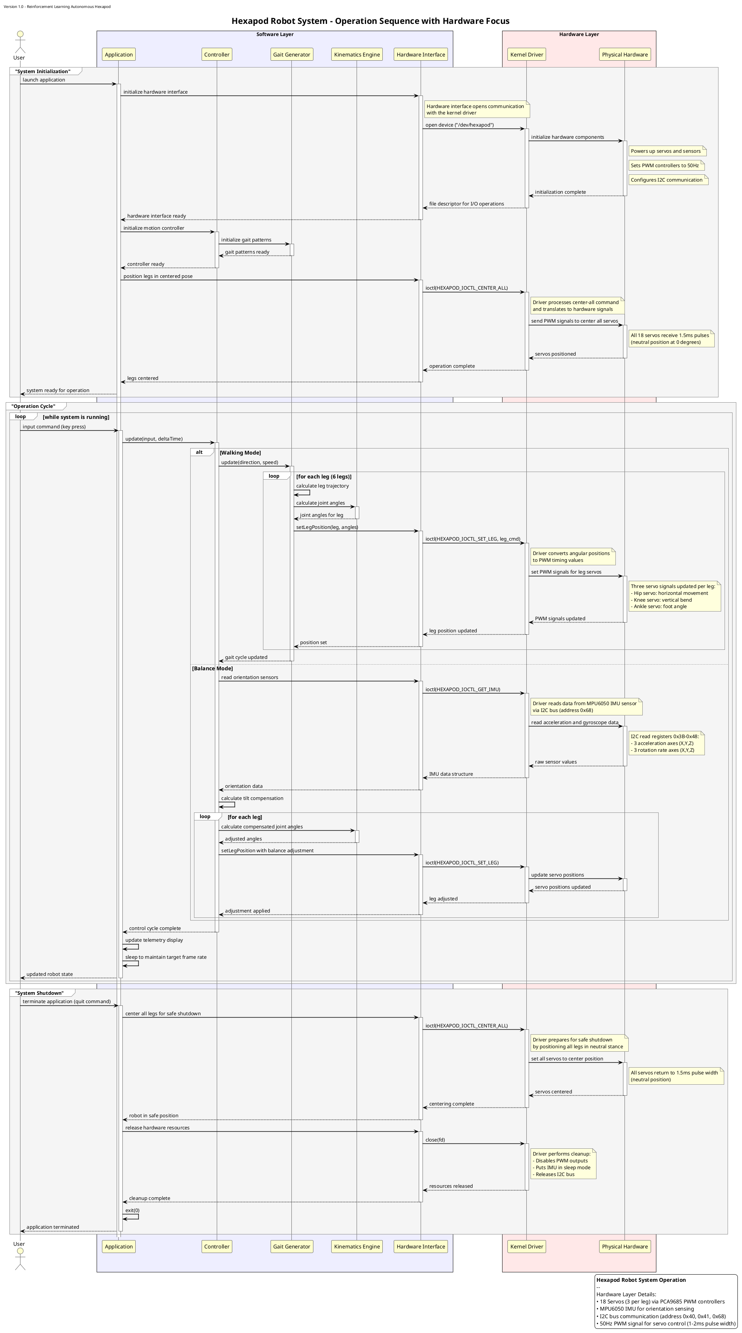
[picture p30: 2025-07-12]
docs/diagrams/image/sequence.png

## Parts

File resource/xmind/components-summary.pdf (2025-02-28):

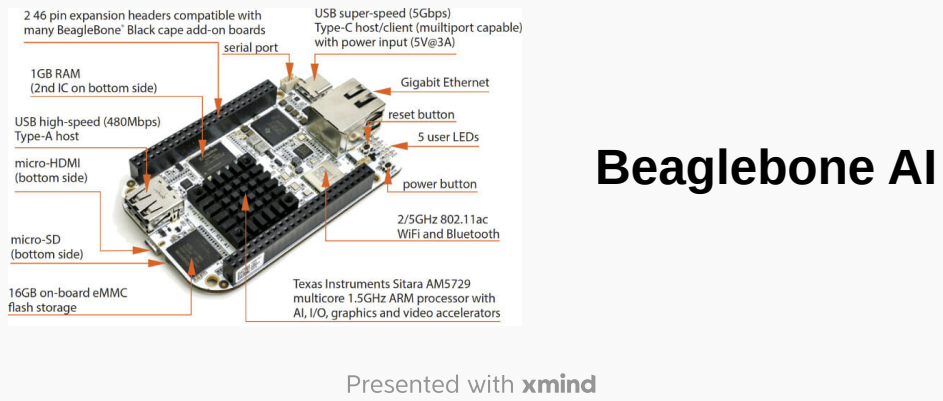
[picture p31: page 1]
Beaglebone AI

Beaglebone AI

### Hardware

### Software

### Power Management

### Controllers

# Hardware

# Hardware Web Cam

### Servo

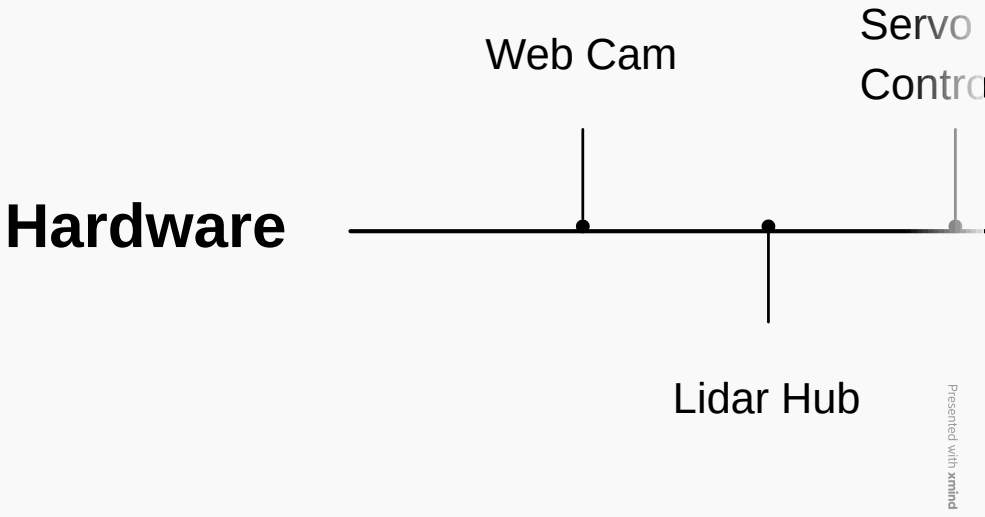
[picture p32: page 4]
Lidar Hub; Servo Contro

Contro Web Cam

### Servo Controller

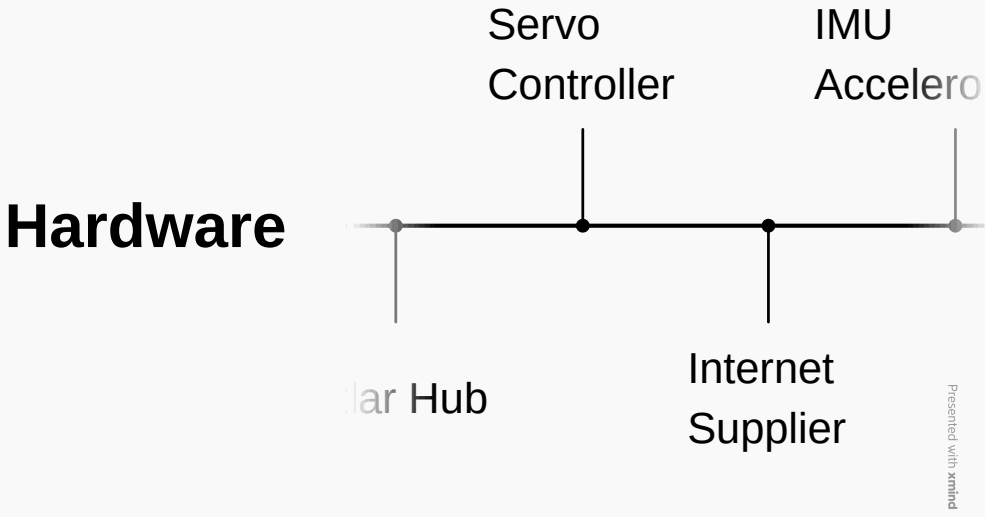
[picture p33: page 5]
Hardware; dar Hub; Internet Supplier; IMU Accelero; Servo Controller

# Hardware

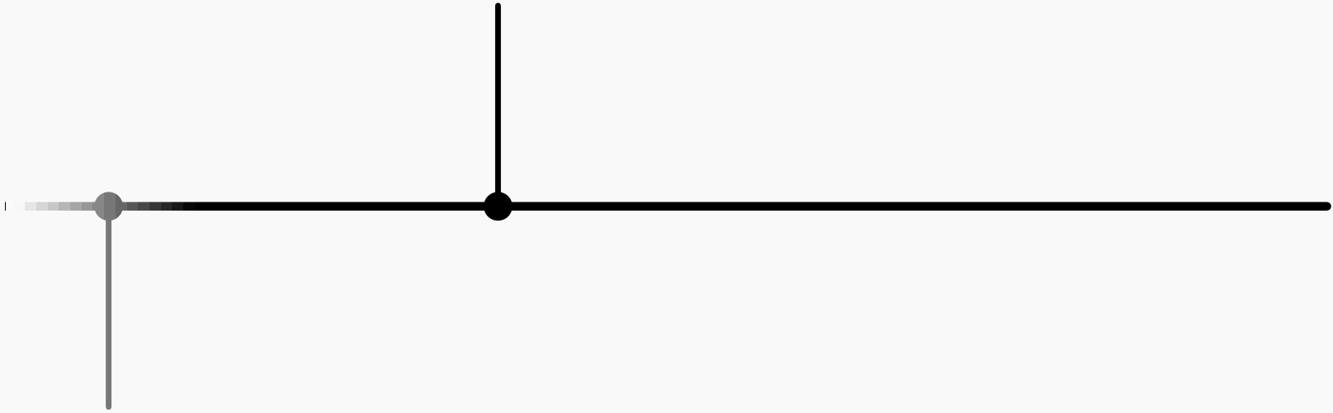
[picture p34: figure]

### nternet upplier

### IMU Accelerometer

### nternet upplier

### IMU Accelerometer

# Web Cam

Overview

Model: Logitech C920

Algorithm

Connection: USB

Port: /dev/video0

Overview

Model: Logitech C920

Algorithm

Connection: USB

Port: /dev/video0

Hardware

# Web Cam

Model: Logitech C920

Algorithm

Connection: USB

Port: /dev/video0

Model: Logitech C920

Algorithm

Connection: USB

Port: /dev/video0

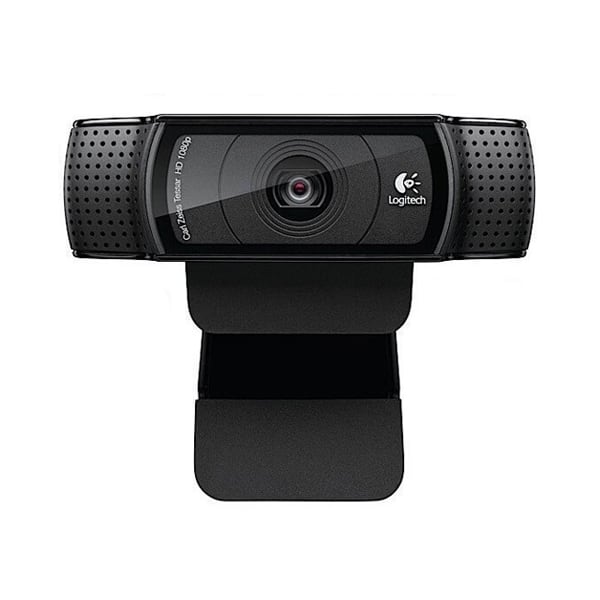
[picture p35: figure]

# Overview

# Overview

Camera module type (e.g., USB, MIPI CSI, SPI, etc.)

Resolution, FPS, and sensor details

Purpose: Vision-based navigation, obstacle detection, AI-based movement

# Algorithm

Frame capture and processing (OpenCV, GStreamer)

Object detection & tracking (YOLO, MobileNet, etc.)

AI-based decision-making (Navigation, obstacle avoidance)

# Lidar Hub

Overview

Model: SLAMTEC RPLIDAR C1

Algorithm

Connection

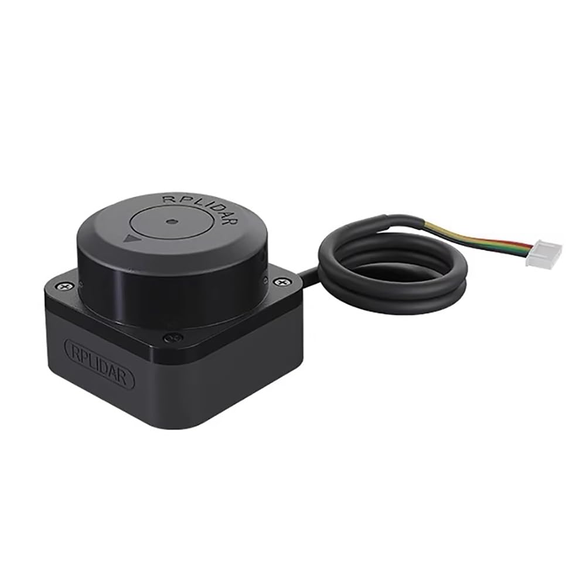
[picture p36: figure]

# Overview

# Overview

Mapping and localization (SLAM)

Obstacle detection and avoidance

Path planning

# Algorithm

SLAM (Simultaneous Localization and Mapping)

Obstacle Detection & Avoidance

Path Planning

# Connection

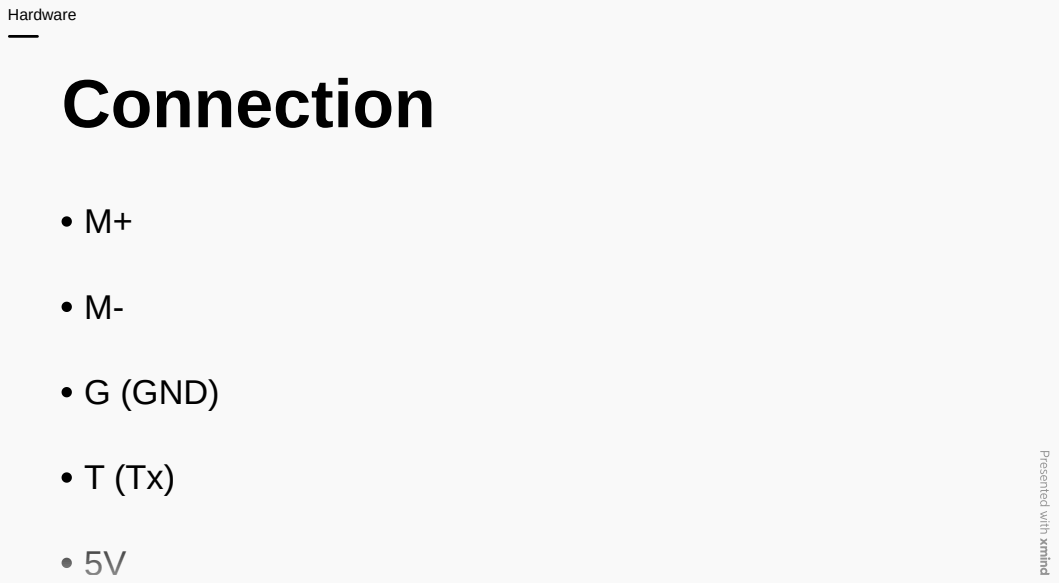
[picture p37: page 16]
G (GND)

# Connection

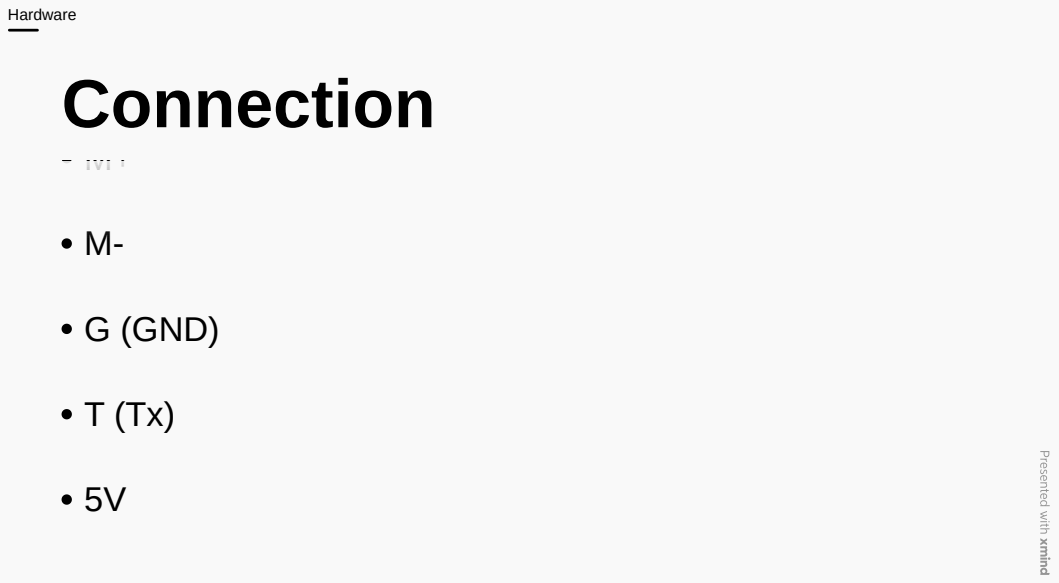
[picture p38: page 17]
G (GND)

# Servo Controller

2x PCA9685 16-channel

Servo 24-channel Controller


## 2x PCA9685 16-channel

# 2x PCA9685 16-channel

Overview

Algorithm

Connection (I2C3)

# Overview

Controlling additional servos beyond the 24-channel controller's capacity

Generating smooth and precise PWM signals

Offloading PWM processing from BeagleBone AI

# Algorithm

Servo Initialization Sequence

Inverse Kinematics for Hexapod Leg Movement

Real-Time Adjustments

# Connection (I2C3)

GND - GND; VCC - 5V; SDA - P9.20; SCL - P9.19

# Connection (I2C3)

VCC - 5V; SDA - P9.20; SCL - P9.19


## Servo 24-channel Controller

# Servo 24-channel Controller

Overview

Algorithm

Connection (UART?)

Output

# Overview

Controlling 18 MG996R servos for hexapod leg movement

Generating smooth and precise PWM signals

Offloading PWM control from the main processor

# Algorithm

Servo Initialization Sequence

Inverse Kinematics for Hexapod Leg Movement

Manual Control (DualSense Integration)

# Connection (UART?)

GND - GND

5V - 5V

Rx - P9.13 (Tx)

# Output

Frequency: 60Hz

PWM: Input cmd

# Internet Supplier

Overview

Model: SIM7600CE

Algorithm

Connection (UART5)


# Overview

# Overview

Enables remote control and real-time telemetry over 4G LTE

Provides GPS positioning for autonomous navigation

Supports data transmission for AI-based control

# Algorithm

Remote Command Handling

GPS-Based Navigation

4G Data Transmission

# Connection (UART5)

GND - GND

Tx - P8.38 (Rx5)

Rx - P8.37 (Tx5)

# IMU Accelerometer

Overview

Model: MPU6050

Algorithm

Connection (I2C3)


# Overview

# Overview

Measures tilt, orientation, and movement of the hexapod

Provides real-time feedback for balance control

Helps in stabilization algorithms for smooth movement

# Algorithm

Balance Correction Algorithm

PID Controller for Stability

# Connection (I2C3)

GND - GND

VCC - 5V

SDA - P9.20

SCL - P9.19

# Software

# Software

Project Overview; System Architecture; Features; Prerequisities

Hexapod Robot Control System

# Software

Project Overview; System Architecture; Features; Prerequisities

# Hexapod Robot Control System

A comprehensive control system for a six-legged robot (hexapod) using BeagleBone AI

Featuring both kernel-space drivers and user-space applications.

Software

# Project Overview

Kernel drivers for servo control (PCA9685) and IMU sensor (MPU6050).

User-space libraries for kinematics and gait control.

Test utilities and example applications.

Comprehensive documentation and hardware guides.

Software

# System Architecture

kernel_driver/: Linux kernel device drivers.

user_space/: User applications and libraries.

docs/: Documentation.

scripts/: Build and utility scripts.

Software

# Features

Software

Multiple gait patterns (tripod, wave, ripple).

Real-time IMU feedback.

Inverse kinematics for precise leg control.

Hardware abstraction layer.

Comprehensive test suite.

# Features

Software

Inverse kinematics for precise leg control.

Hardware abstraction layer.

Comprehensive test suite.

Interactive debugging tools.

# Prerequisities

I2C enabled (bus 3).; MPU6050 IMU sensor.; 2x PCA9685 PWM controllers.; Software

BeagleBone AI running Linux kernel 4.14+.

18x servo motors (MG996R recommended).

# Prerequisities

I2C enabled (bus 3).; MPU6050 IMU sensor.; 2x PCA9685 PWM controllers.; Software

18x servo motors (MG996R recommended).

# Power Management

# Power Management

4x Panasonic Li-ion Battery

Battery Management System (2S - 2P)

Voltage Regulator 20A 300W


## 4x Panasonic Li-ion Battery

Power Management


## Battery Management System (2S -

2P)

Power Management


## Voltage Regulator 20A

300W

Power Management

# Controllers


# 18x Servo

# 18x Servo

Connection

Algorithm

Model: MG996

Overview

# Connection

GND - GND

VCC - 5V

V++ - 5V

18x Servo

# Algorithm

Angle-to-PWM Conversion

MG996R moves based on the pulse width

18x Servo

# Overview

Controls the hexapod's leg movements

Receives positioning commands from PCA9685

18x Servo

# Thank you

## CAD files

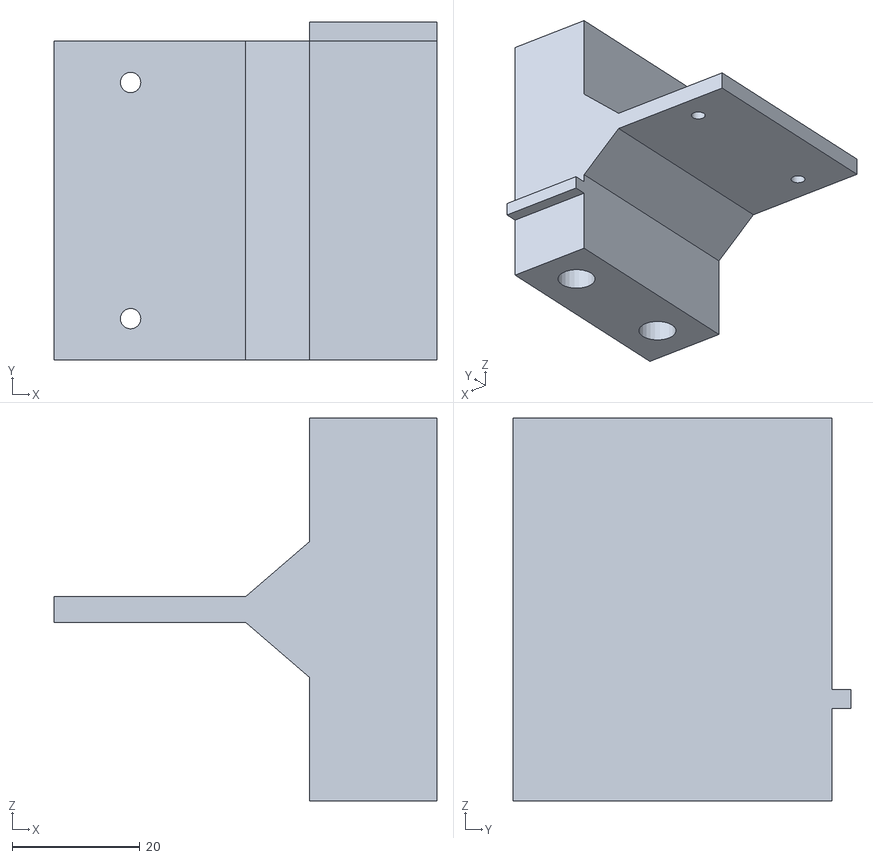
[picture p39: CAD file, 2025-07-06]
hardware/References/IR_Distance_Sensor/3D/SensorBase.stl
60.0 x 53.0 x 60.0

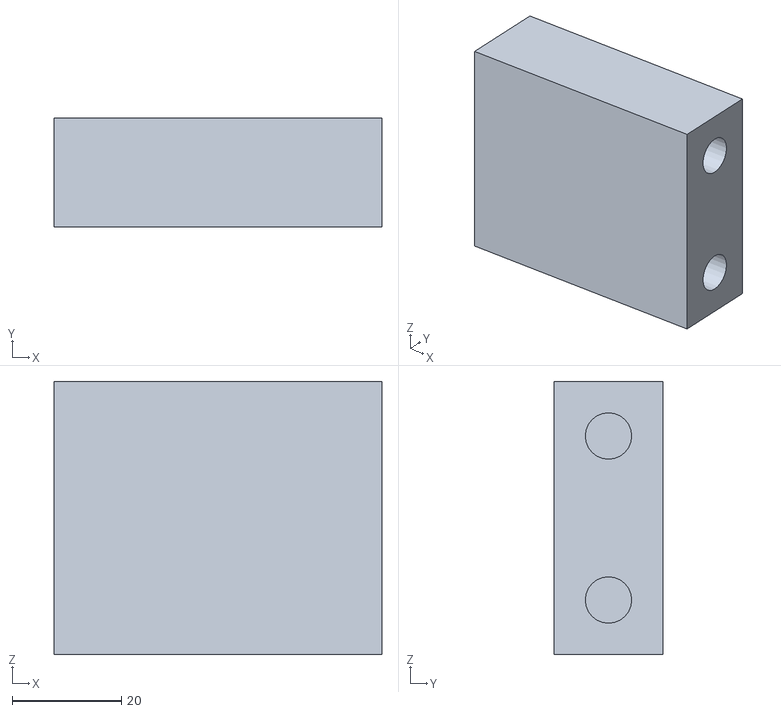
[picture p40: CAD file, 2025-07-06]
hardware/References/IR_Distance_Sensor/3D/Holder.stl
60.0 x 20.0 x 50.0

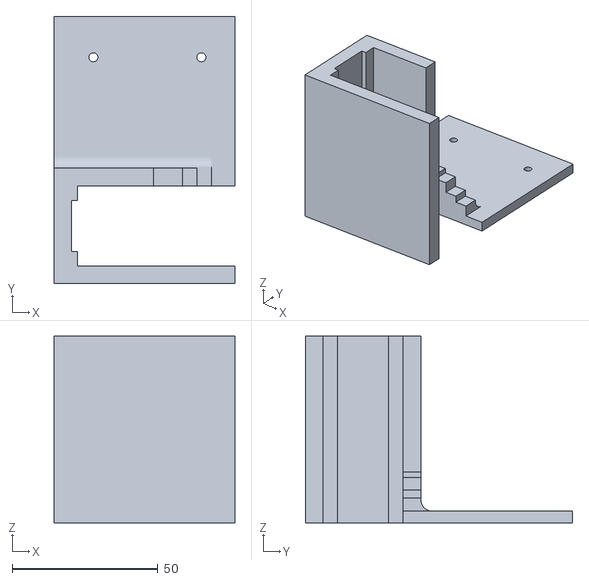
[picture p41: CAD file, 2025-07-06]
hardware/References/IR_Distance_Sensor/3D/Sensor_table.stl
62.0 x 91.5 x 64.0

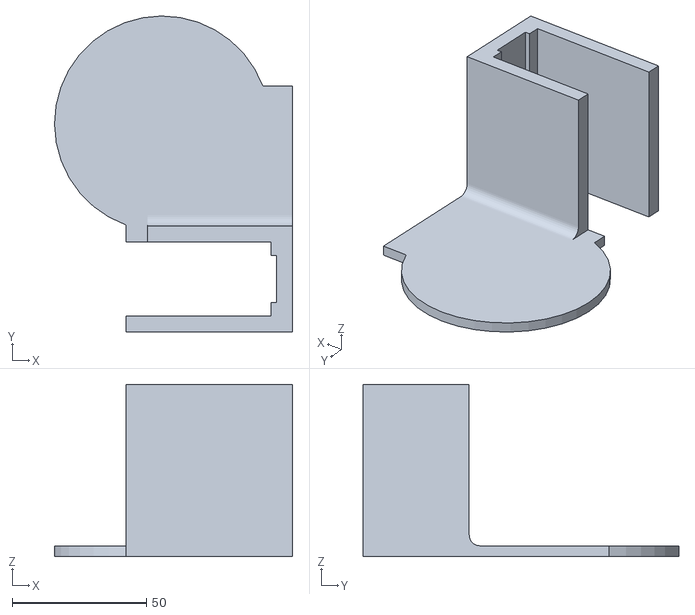
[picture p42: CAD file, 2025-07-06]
hardware/References/IR_Distance_Sensor/3D/Distance_table.stl
88.5 x 117.5 x 64.0

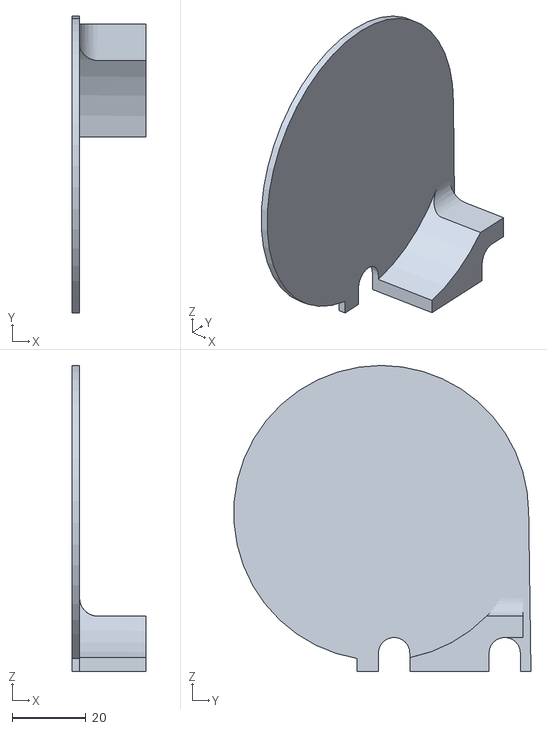
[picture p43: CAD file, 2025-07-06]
hardware/References/IR_Distance_Sensor/3D/Distance.stl
20.0 x 80.5 x 83.0

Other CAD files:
hardware/References/IR_Distance_Sensor/3D/Distance.dwg
hardware/References/IR_Distance_Sensor/3D/Holder.dwg
hardware/References/IR_Distance_Sensor/3D/SensorBase.dwg
hardware/References/IR_Distance_Sensor/3D/Sensor_table.dwg

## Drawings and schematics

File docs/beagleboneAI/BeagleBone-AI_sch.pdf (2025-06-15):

# BeagleBone AI AM57x

# SCHEMATIC PAGE

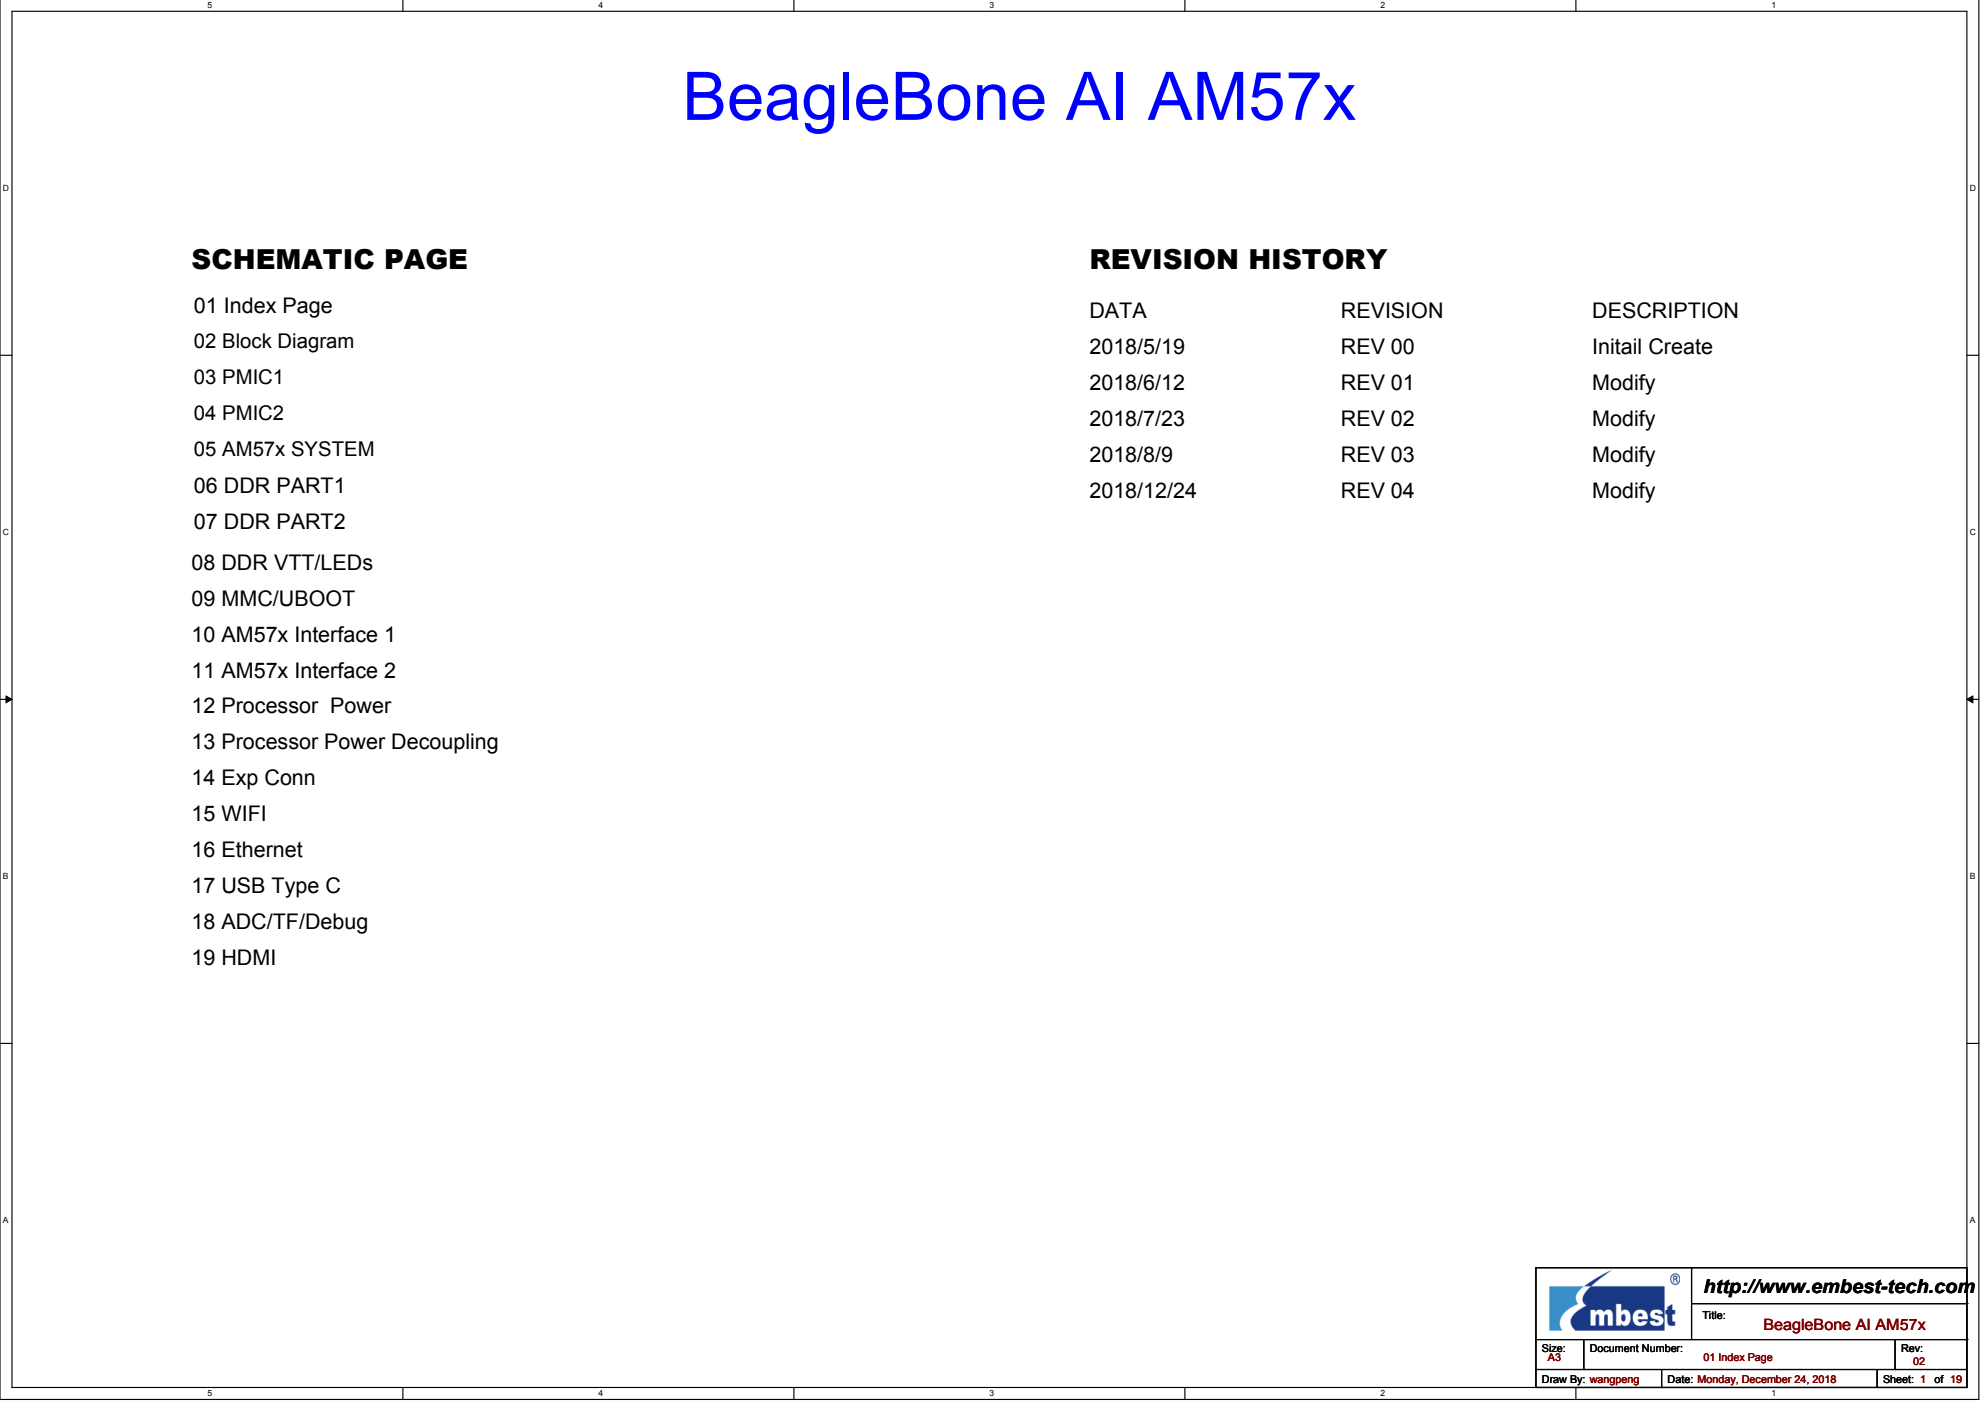
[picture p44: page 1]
07 DDR PART2; 06 DDR PART1; 04 PMIC2; 03 PMIC1; 05 AM57x SYSTEM; 02 Block Diagram; 01 Index Page; REVISION HISTORY; DATA; REVISION; DESCRIPTION; REV 00; Initail Create; REV 01; Modify; REV 02; REV 03; REV 04; Title:; Size:; Document Number:; Rev:; Draw By:; Date:; Sheet:; BeagleBone AI AM57x; wangpeng; Monday, December 24, 2018

08 DDR VTT/LEDs
09 MMC/UBOOT
10 AM57x Interface 1
11 AM57x Interface 2
12 Processor Power
13 Processor Power Decoupling
14 Exp Conn
15 WIFI
16 Ethernet
17 USB Type C
18 ADC/TF/Debug
19 HDMI

http://www.embest-tech.com

# B e a g l e B o n e A I A M 5 7 x B L O C K D i a g r a m

# D D R 3 L

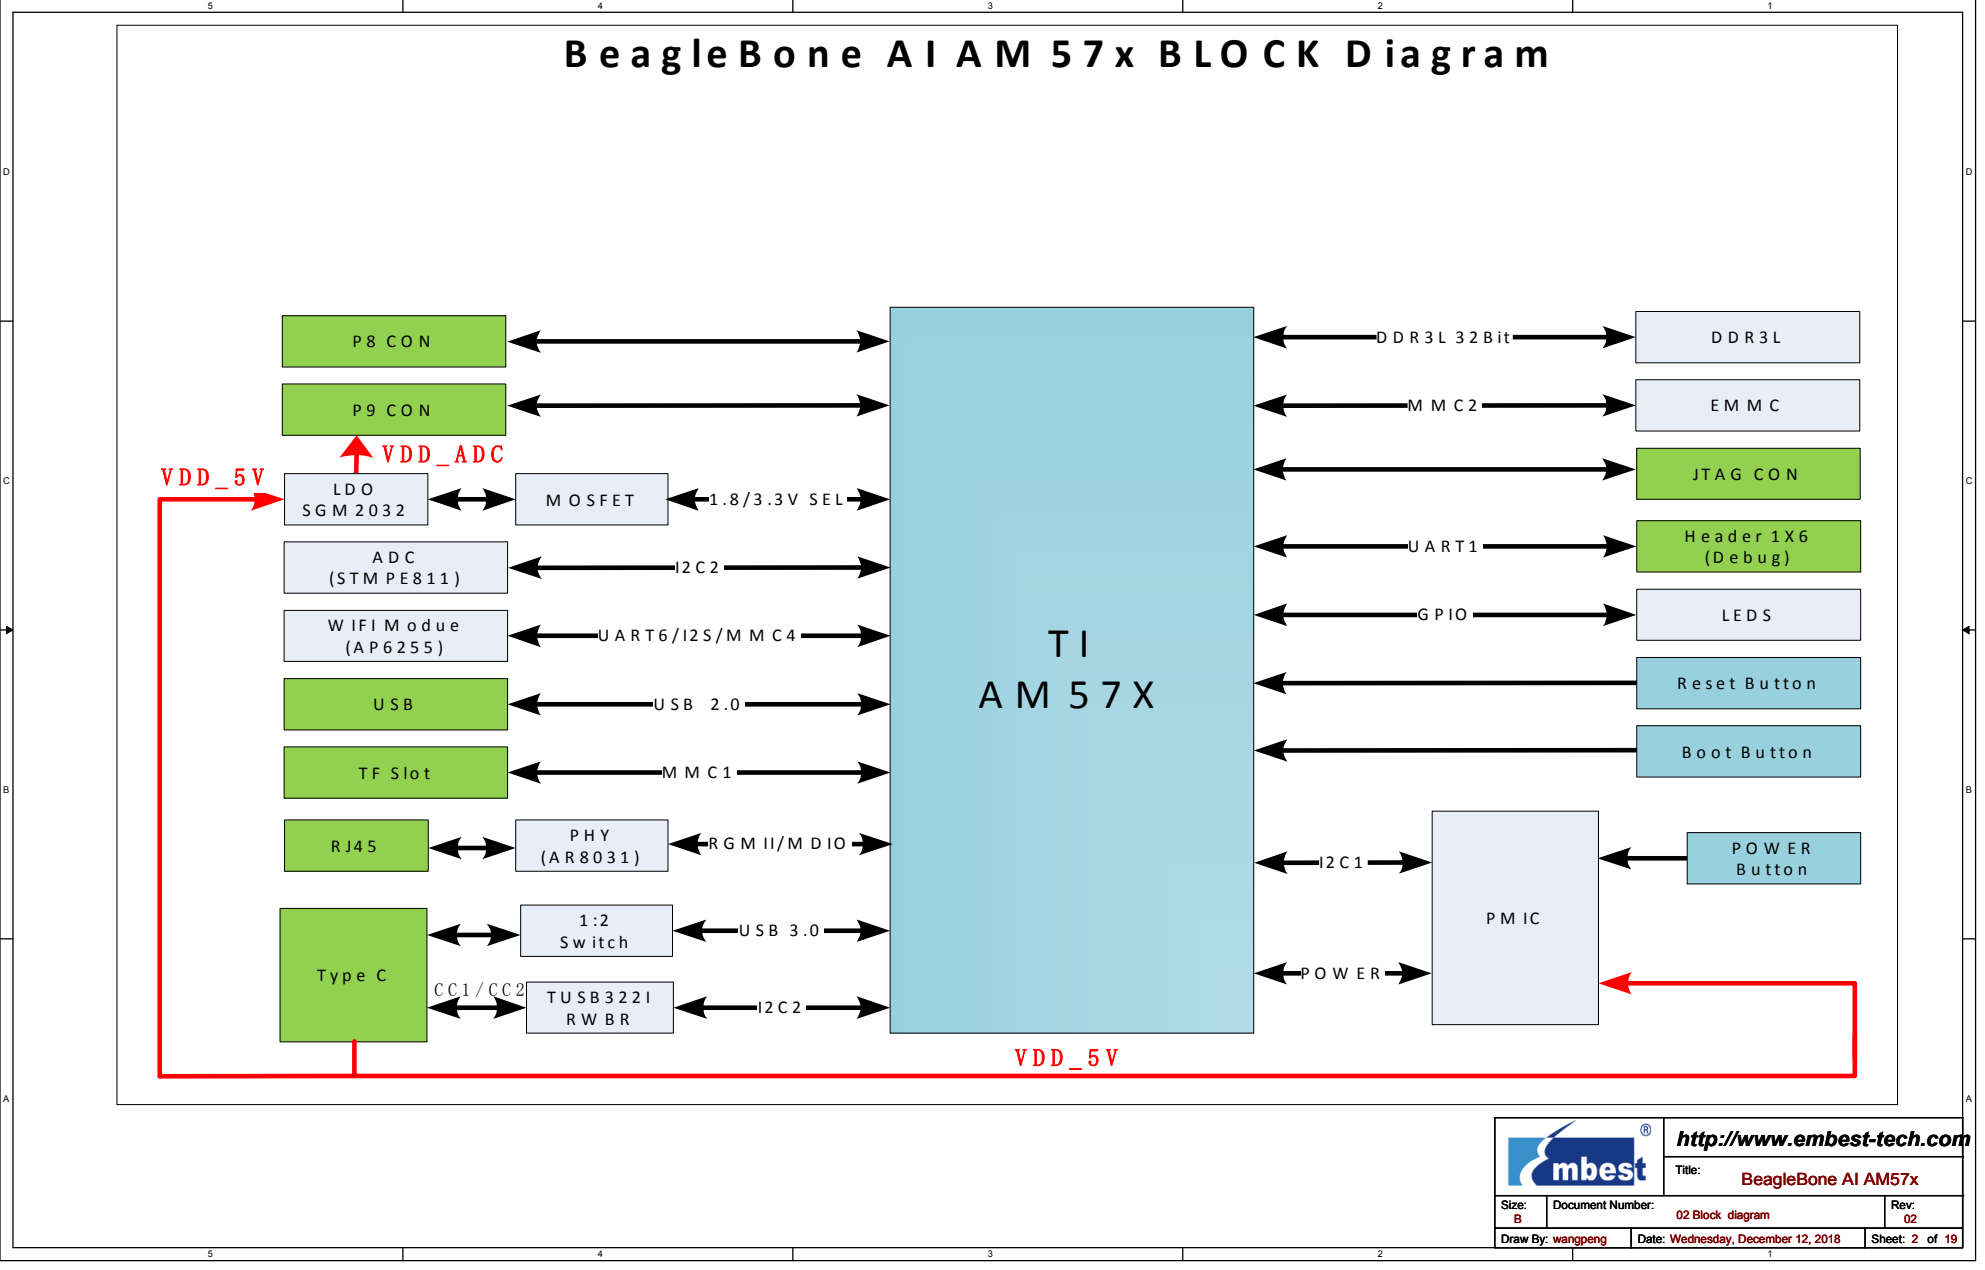
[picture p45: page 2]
Title:; Size:; Document Number:; Rev:; Draw By:; Date:; Sheet:; 02 Block diagram; BeagleBone AI AM57x; wangpeng; Wednesday, December 12, 2018

http://www.embest-tech.com

D | D

16.348MHZ,CL=10PF,

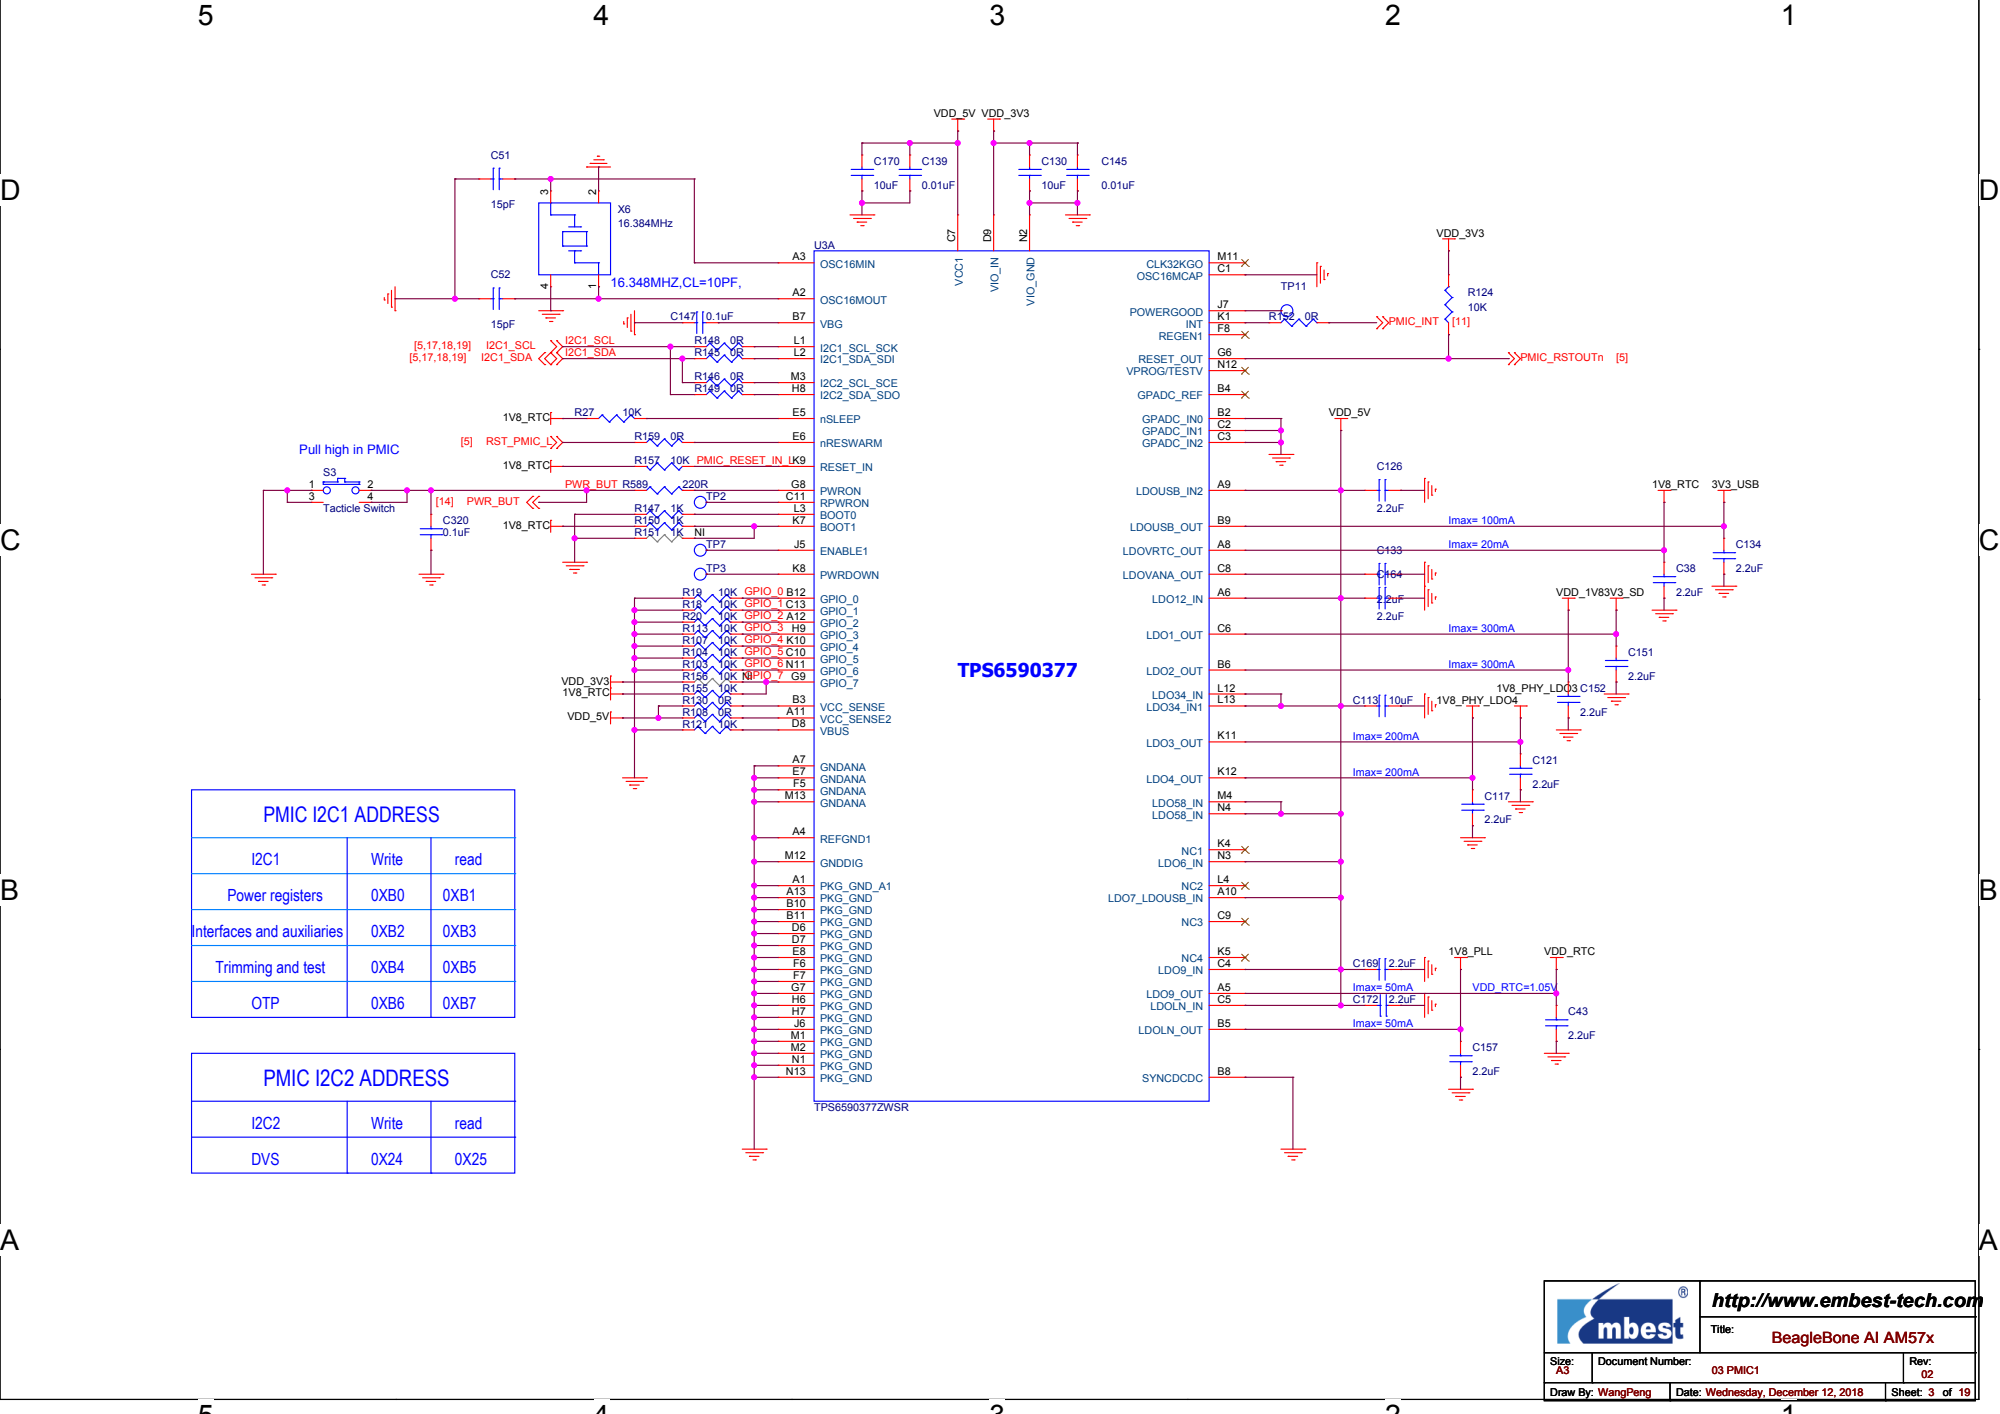
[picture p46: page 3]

Pull high in PMIC

http://www.embest-tech.com

D | D

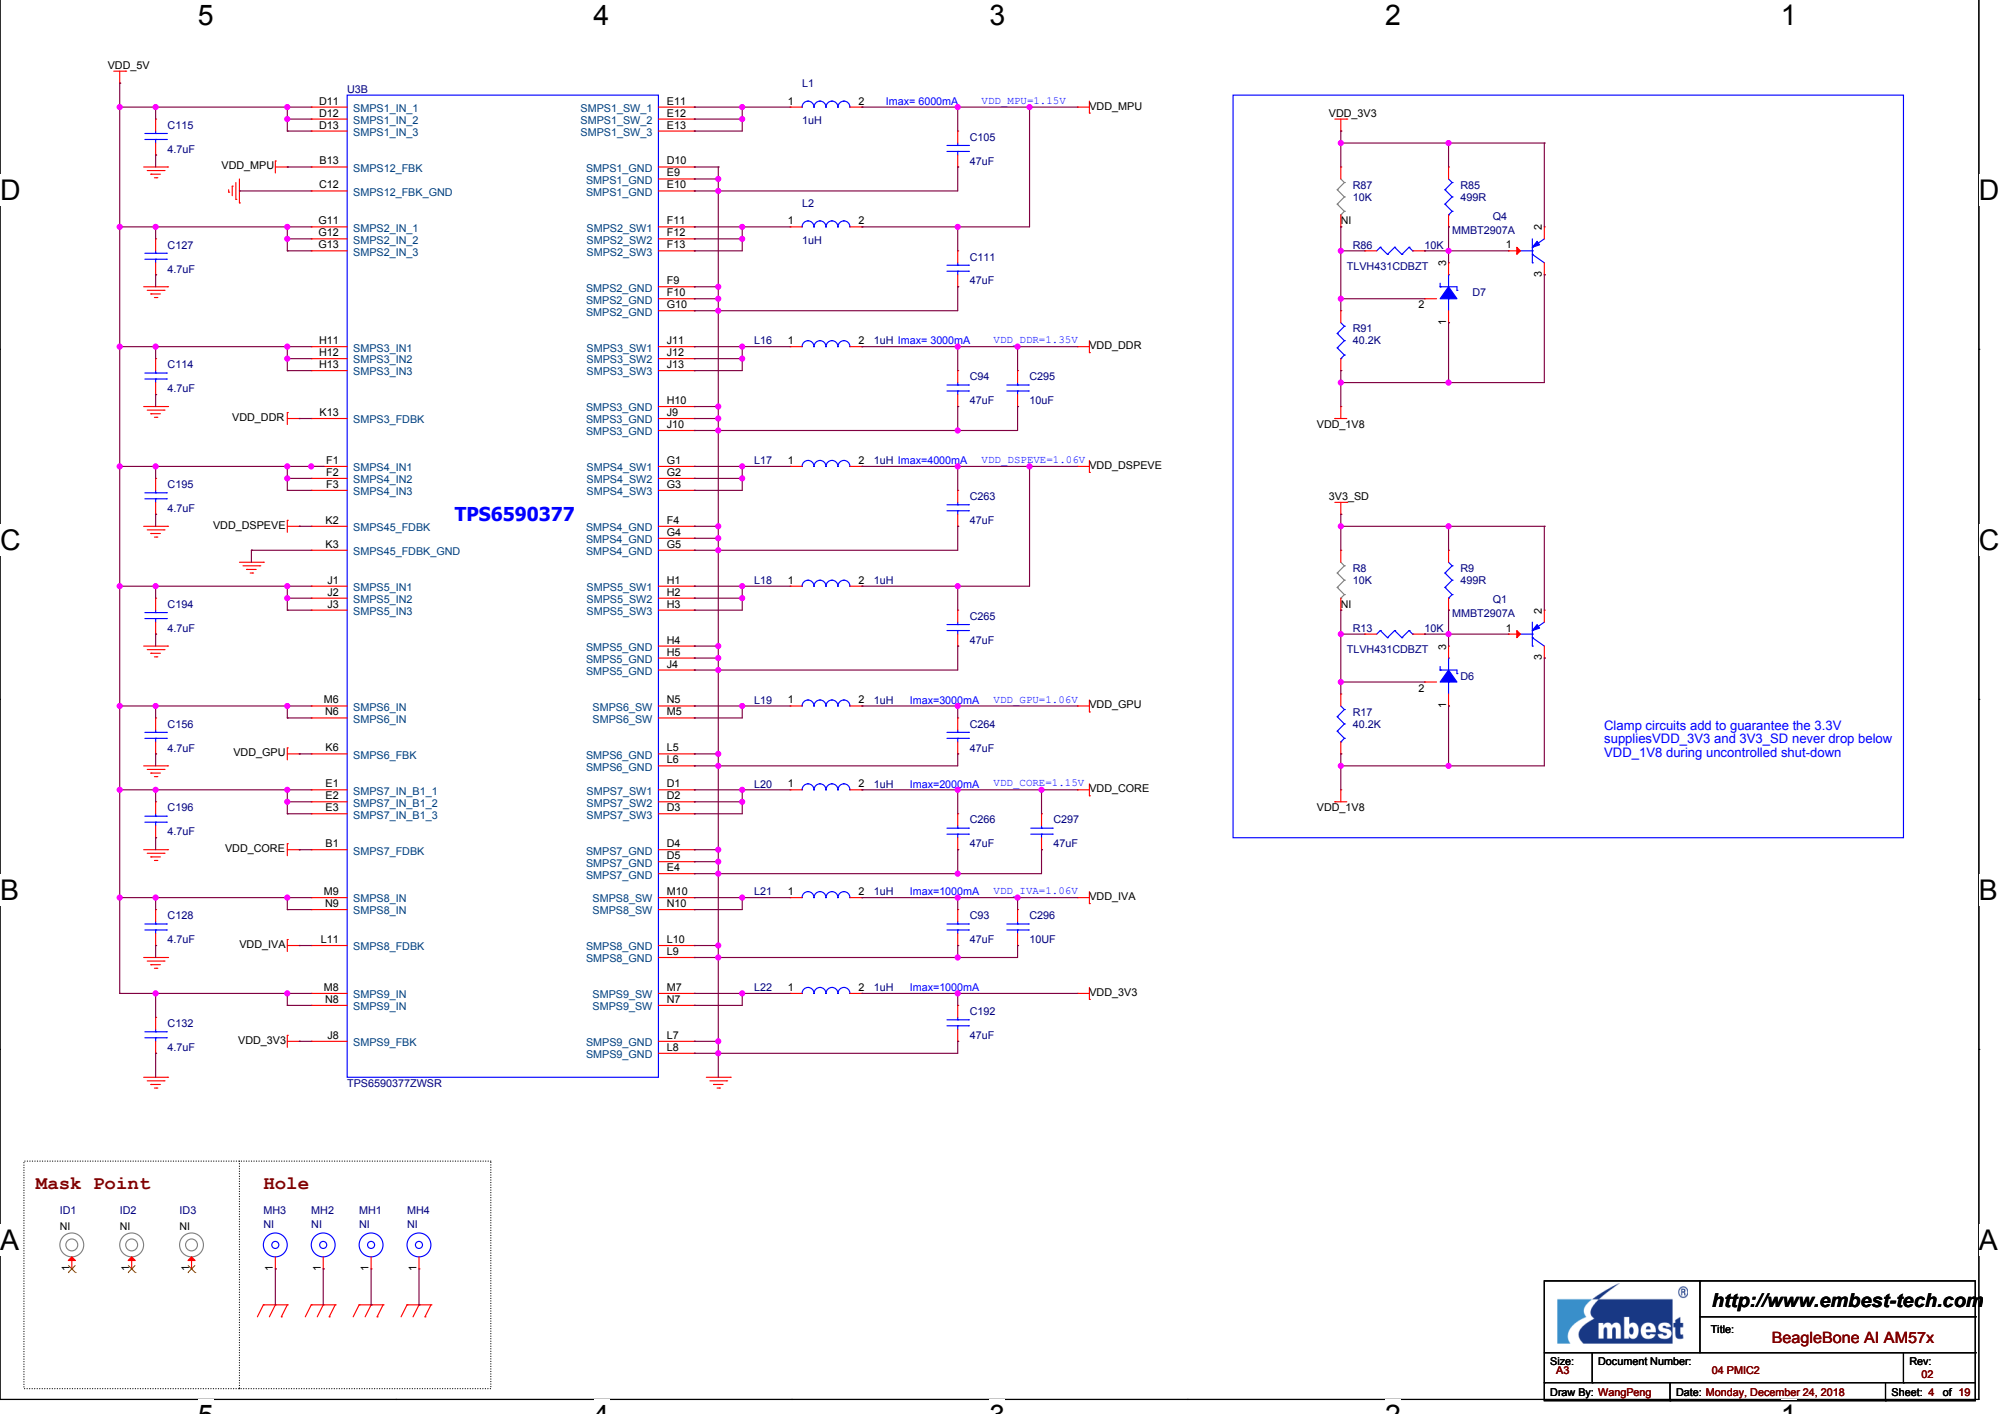
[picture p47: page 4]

Clamp circuits add to guarantee the 3.3V
suppliesVDD_3V3 and 3V3_SD never drop below
VDD_1V8 during uncontrolled shut-down

http://www.embest-tech.com

20MHZ,CL=18PF,

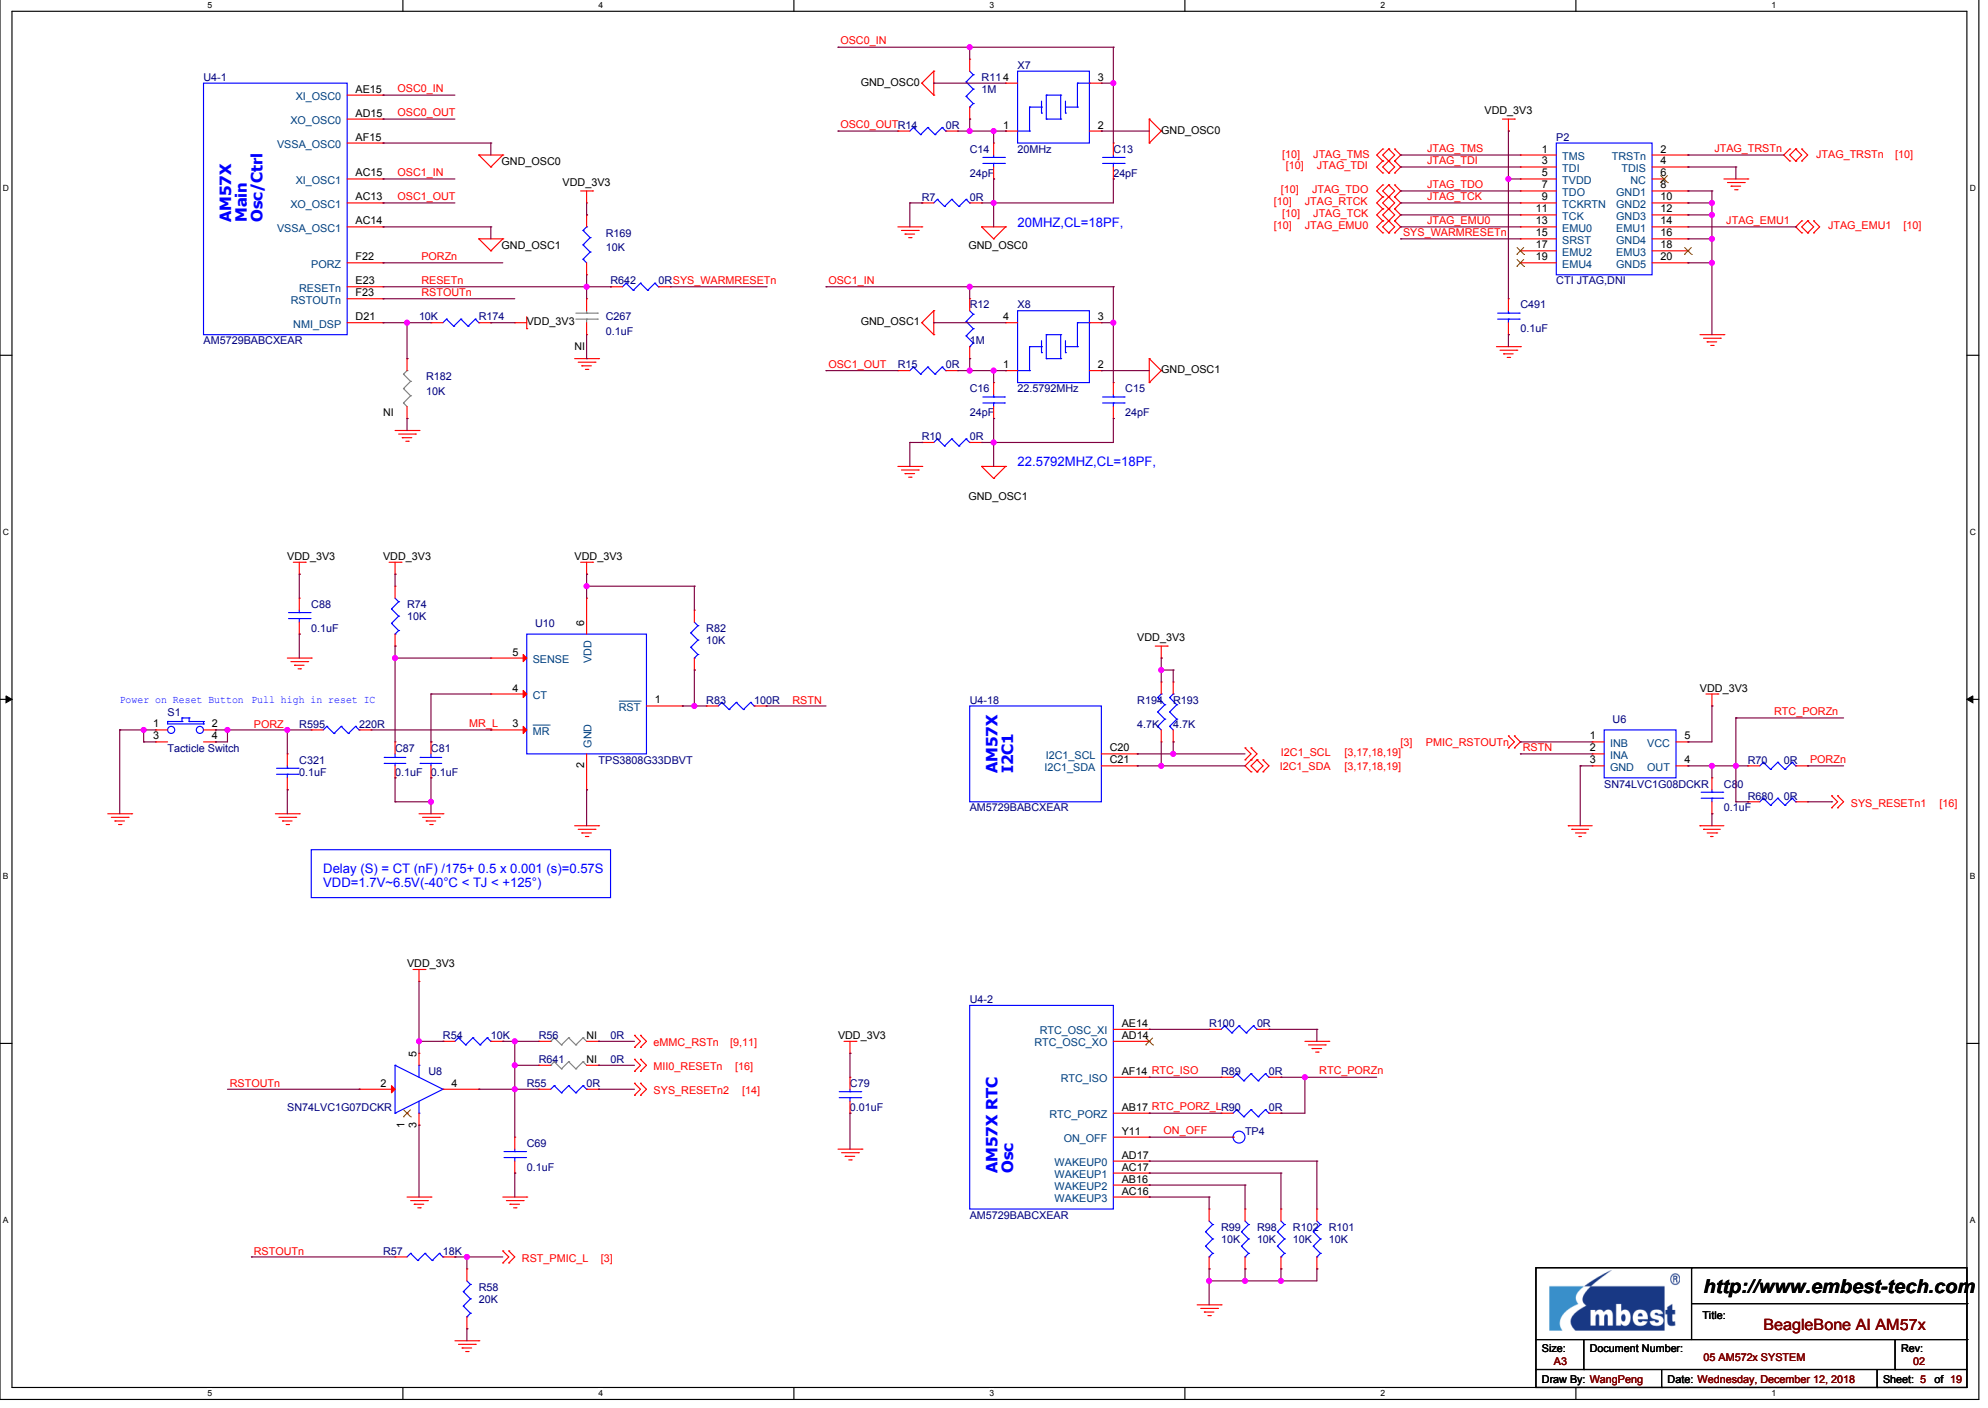
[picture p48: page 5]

Power on Reset Button Pull high in reset IC

http://www.embest-tech.com

D | D

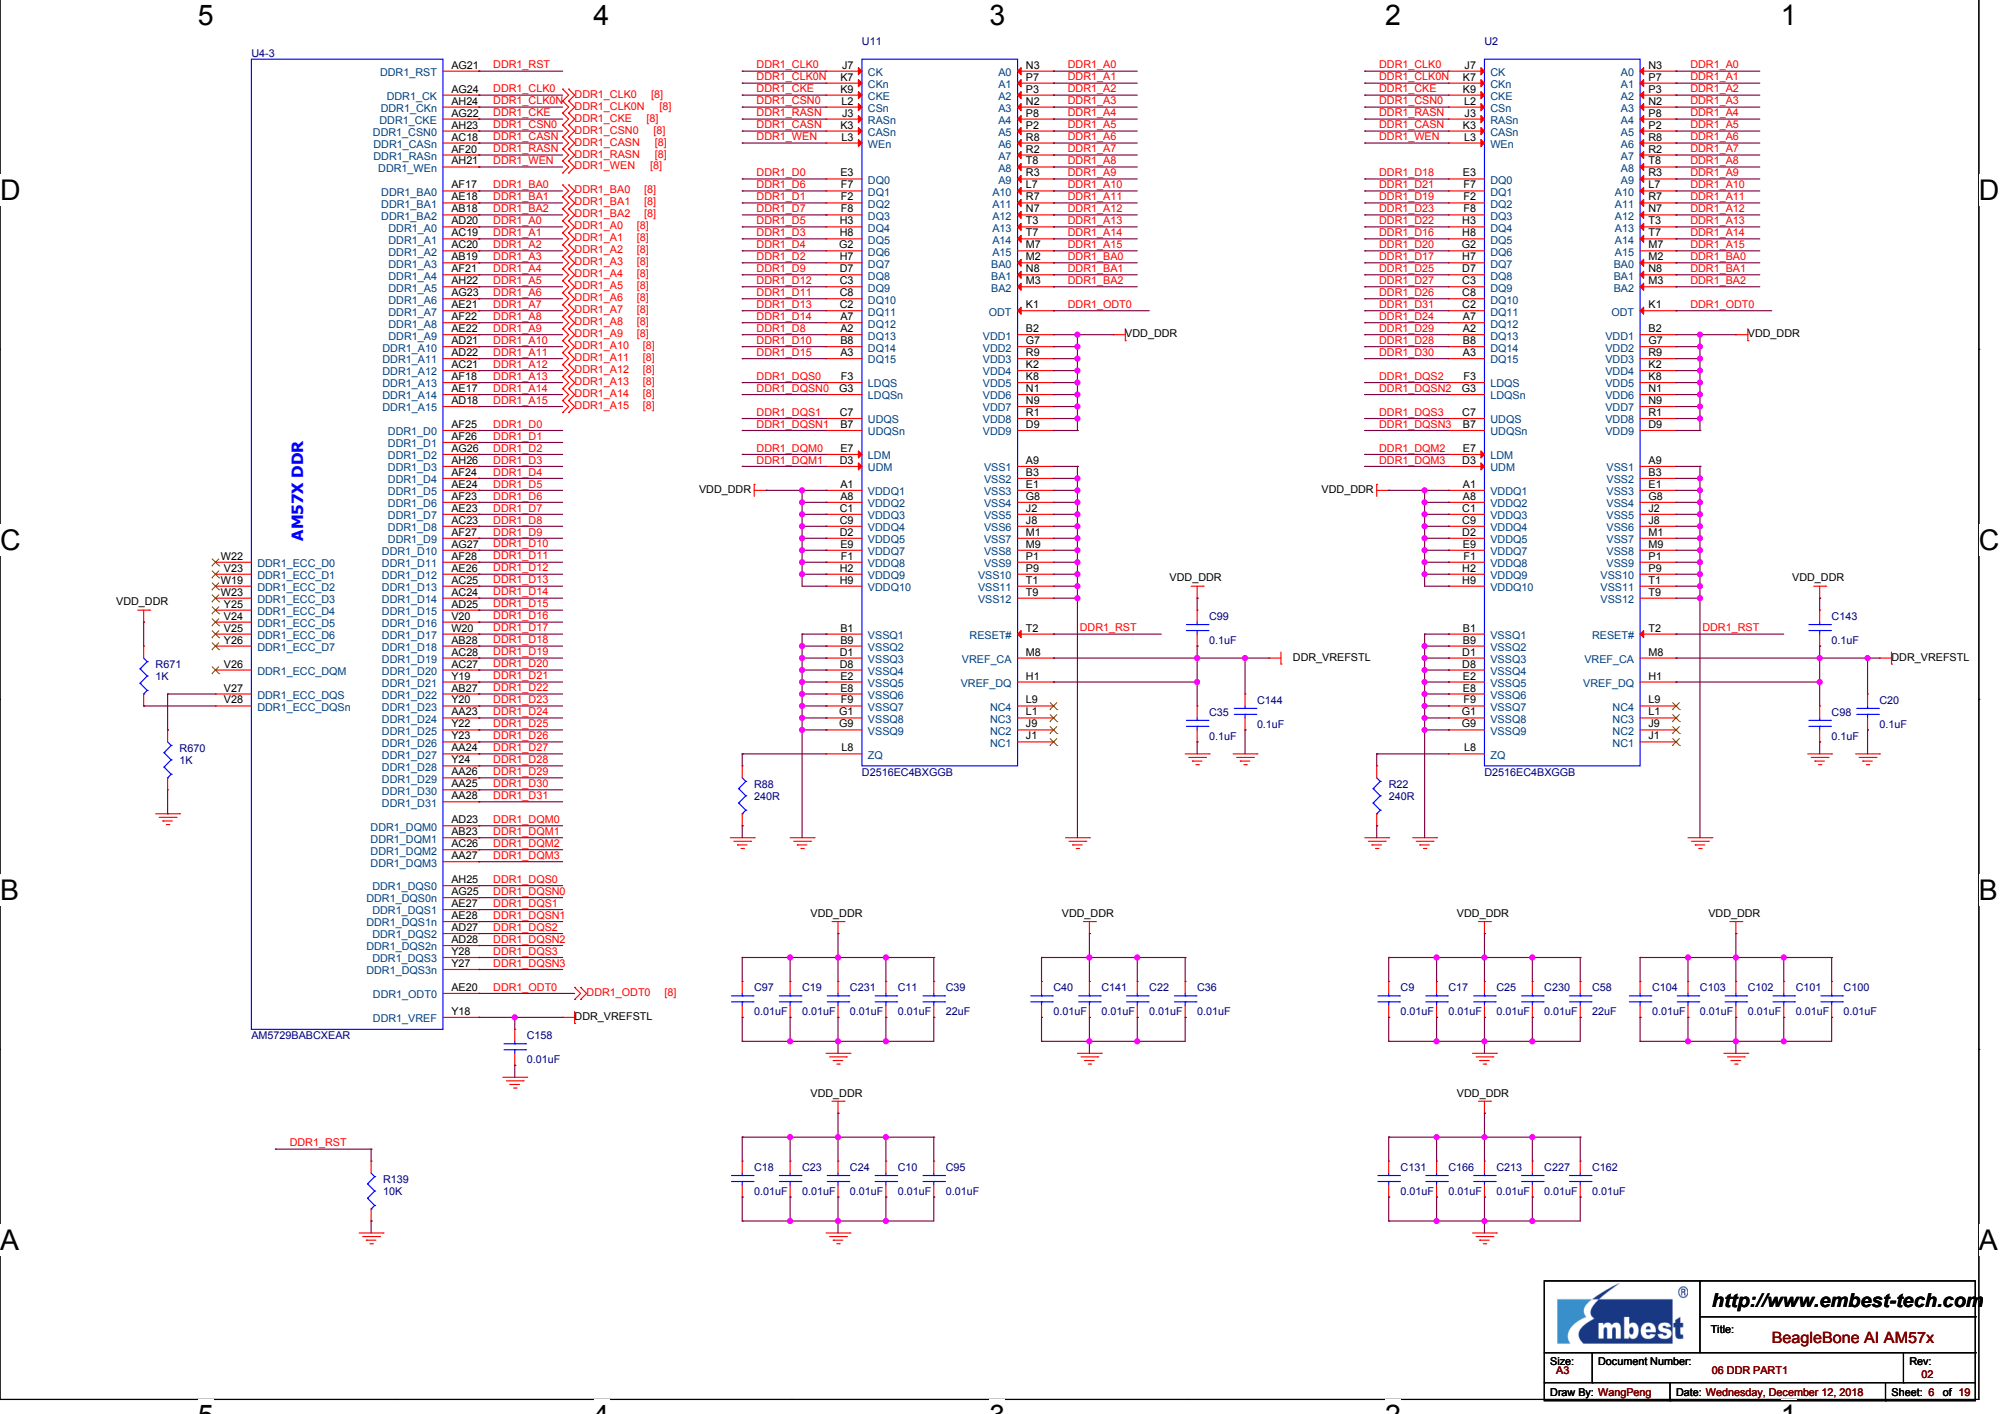
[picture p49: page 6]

http://www.embest-tech.com

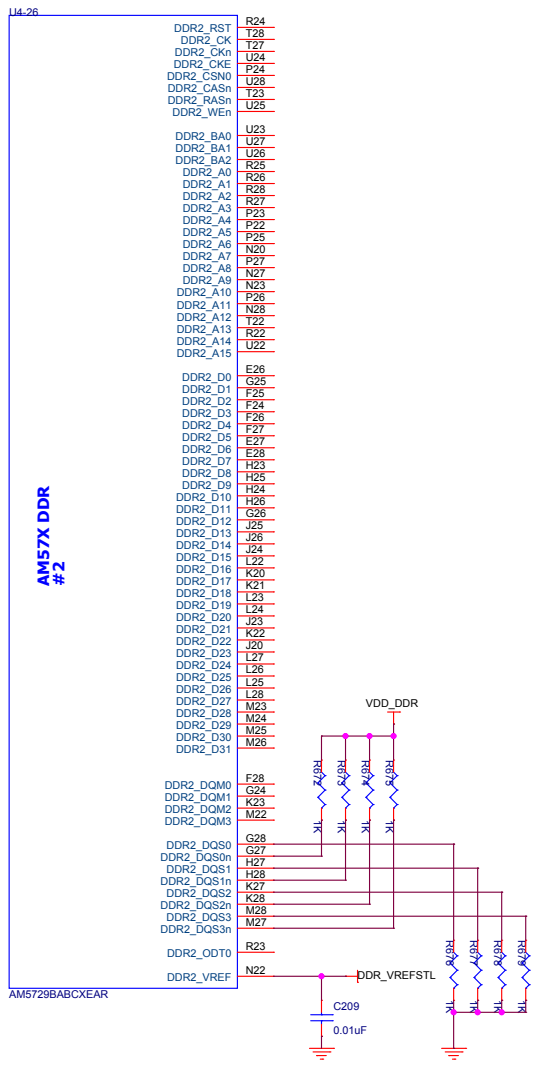
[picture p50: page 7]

http://www.embest-tech.com

### POWER LED

LED | VTT

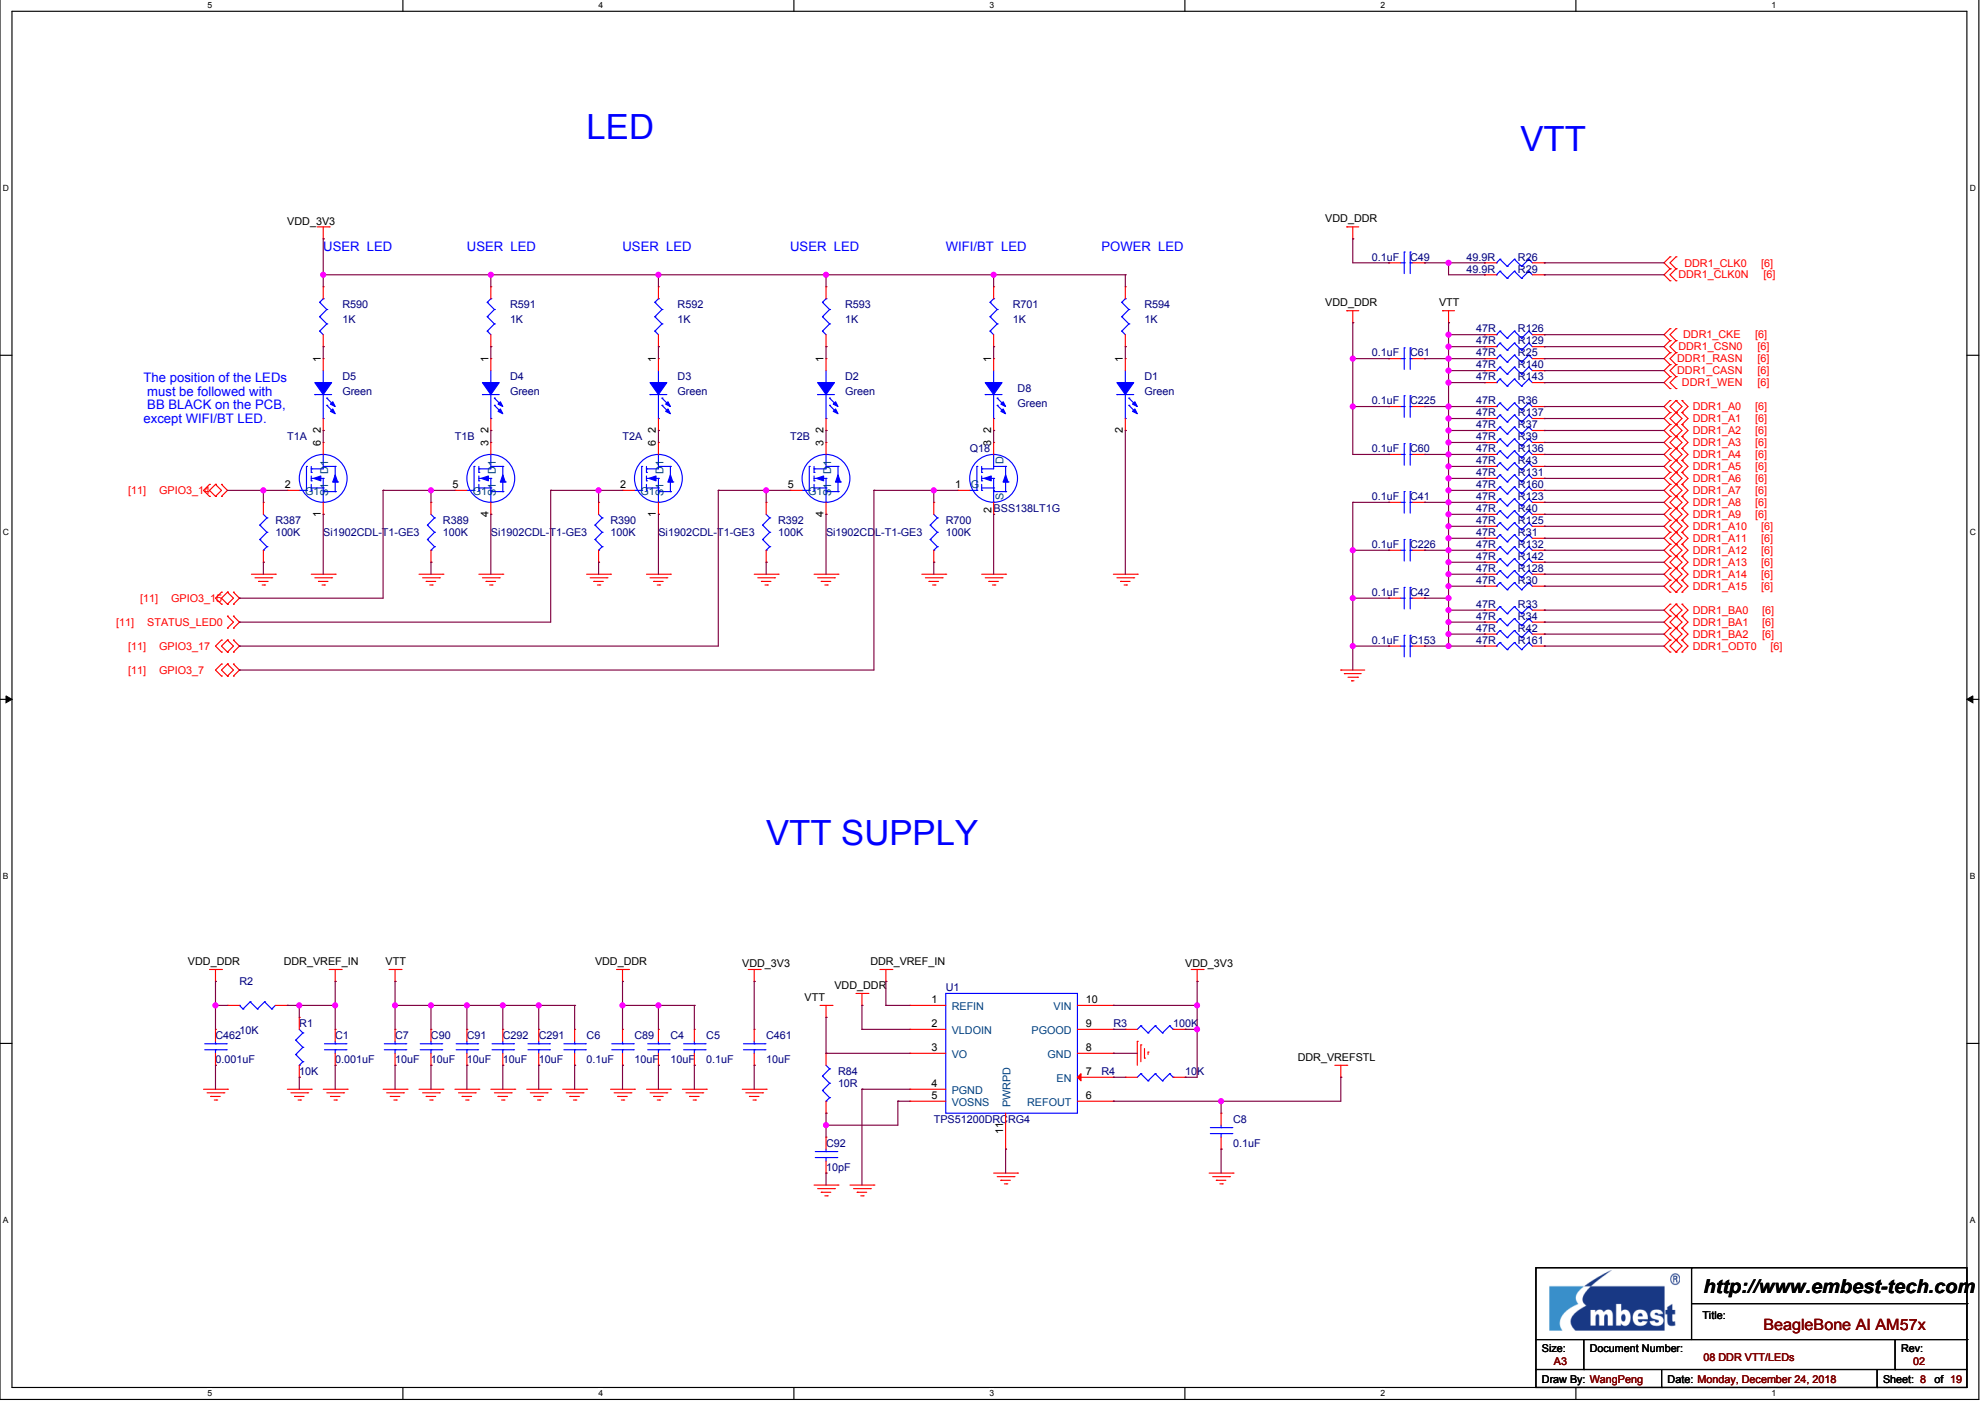
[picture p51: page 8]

The position of the LEDs
must be followed with
BB BLACK on the PCB,
except WIFI/BT LED.

http://www.embest-tech.com

MMC3_DAT2/PR2_MII_MR1_CLK | AC9 R⁶⁰² ¹⁰K | R⁶⁰⁴ ¹⁰K

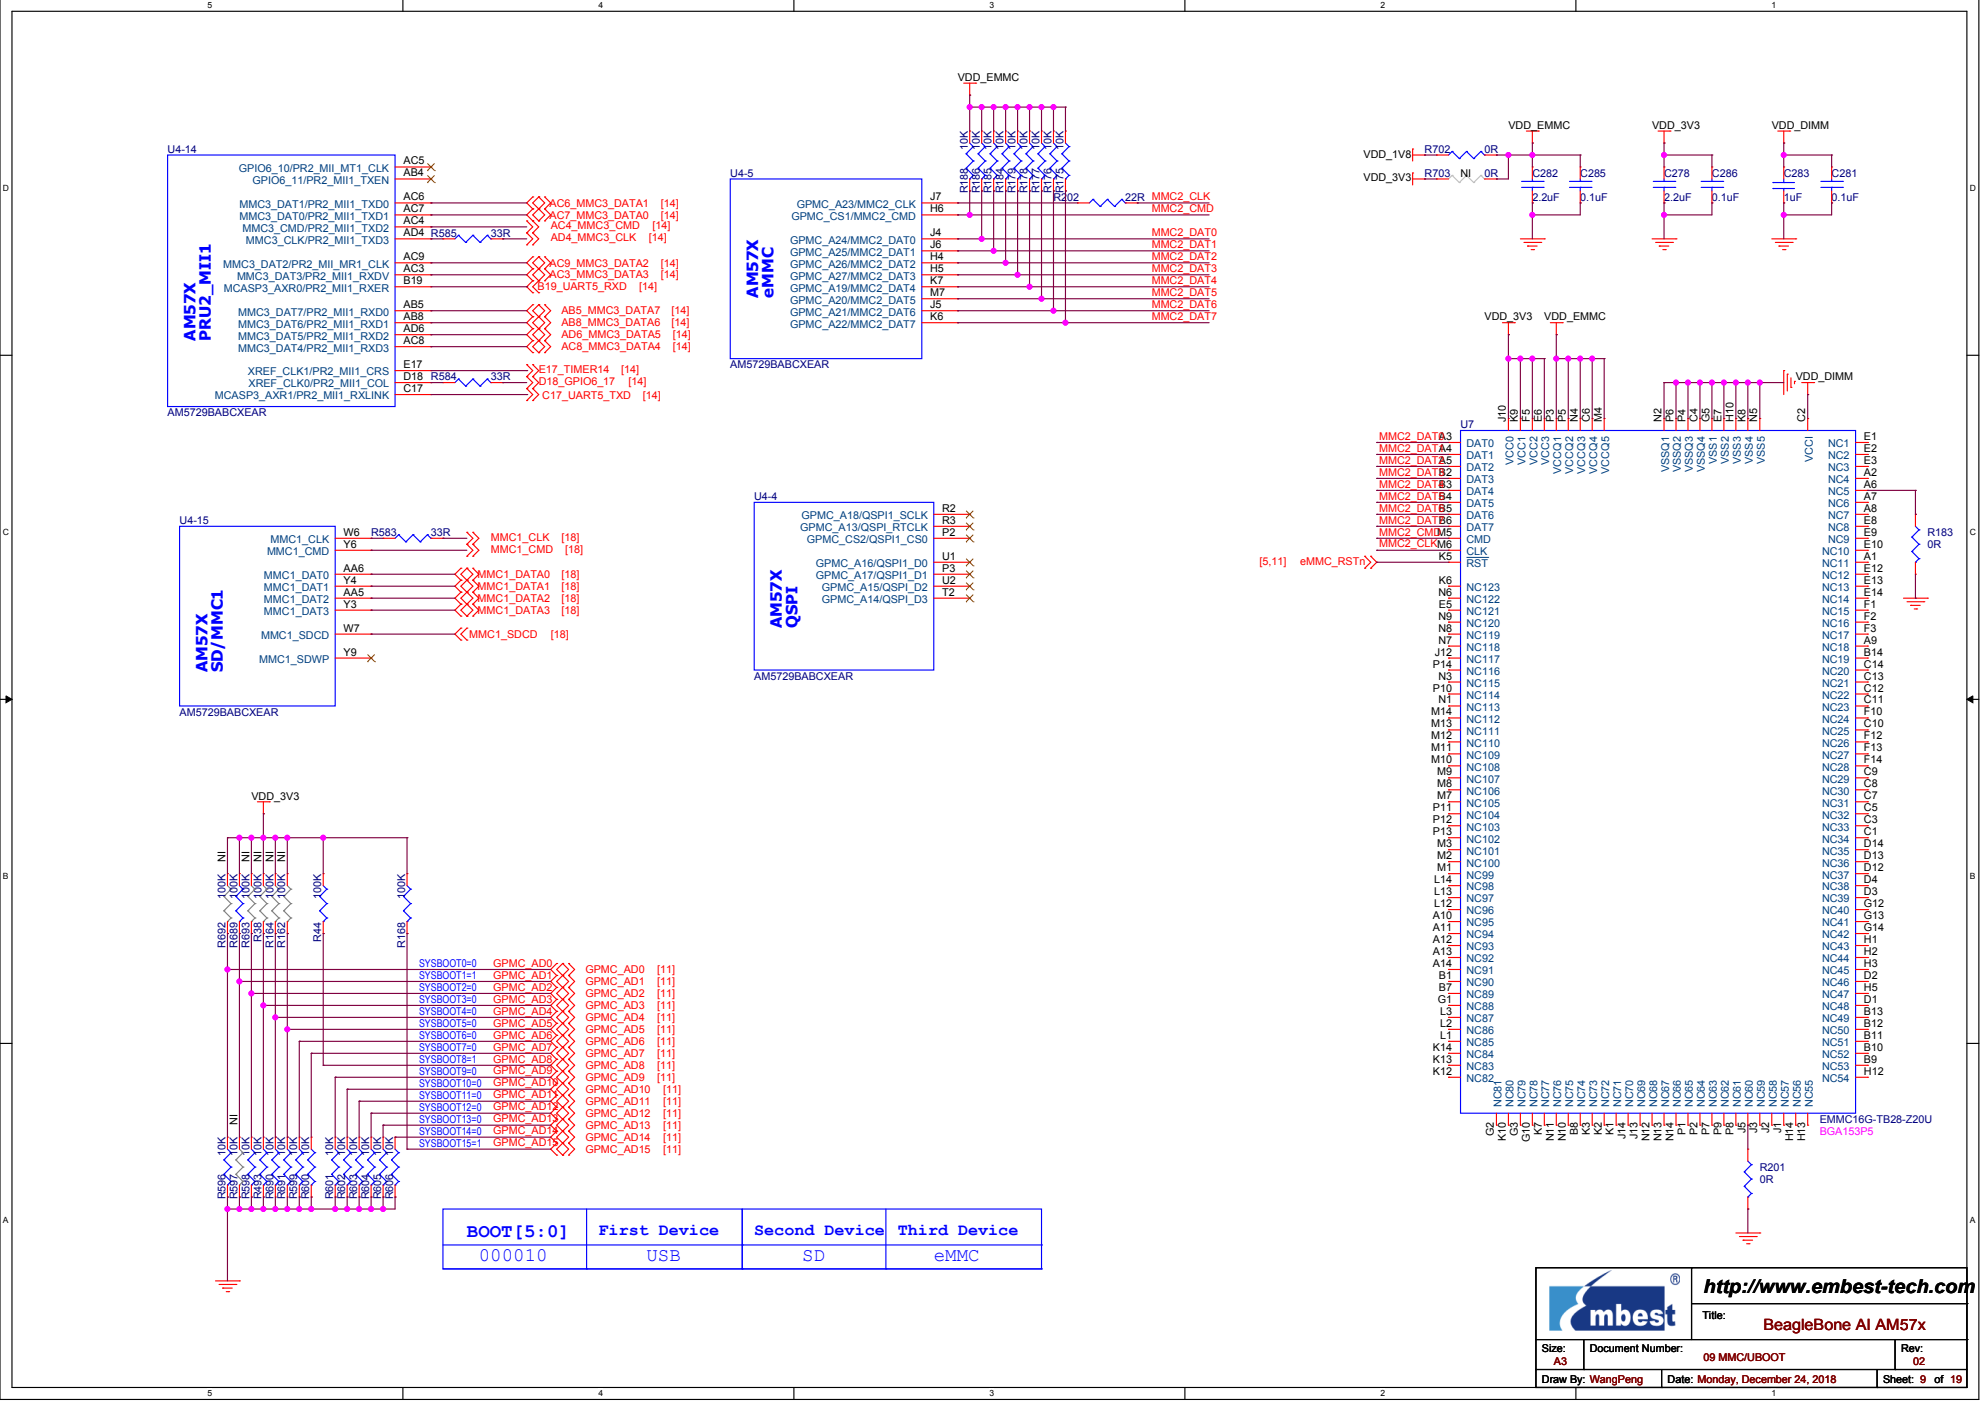
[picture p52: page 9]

http://www.embest-tech.com

D | D

### R97 R96 R92 R93 R94 R95 Should close to

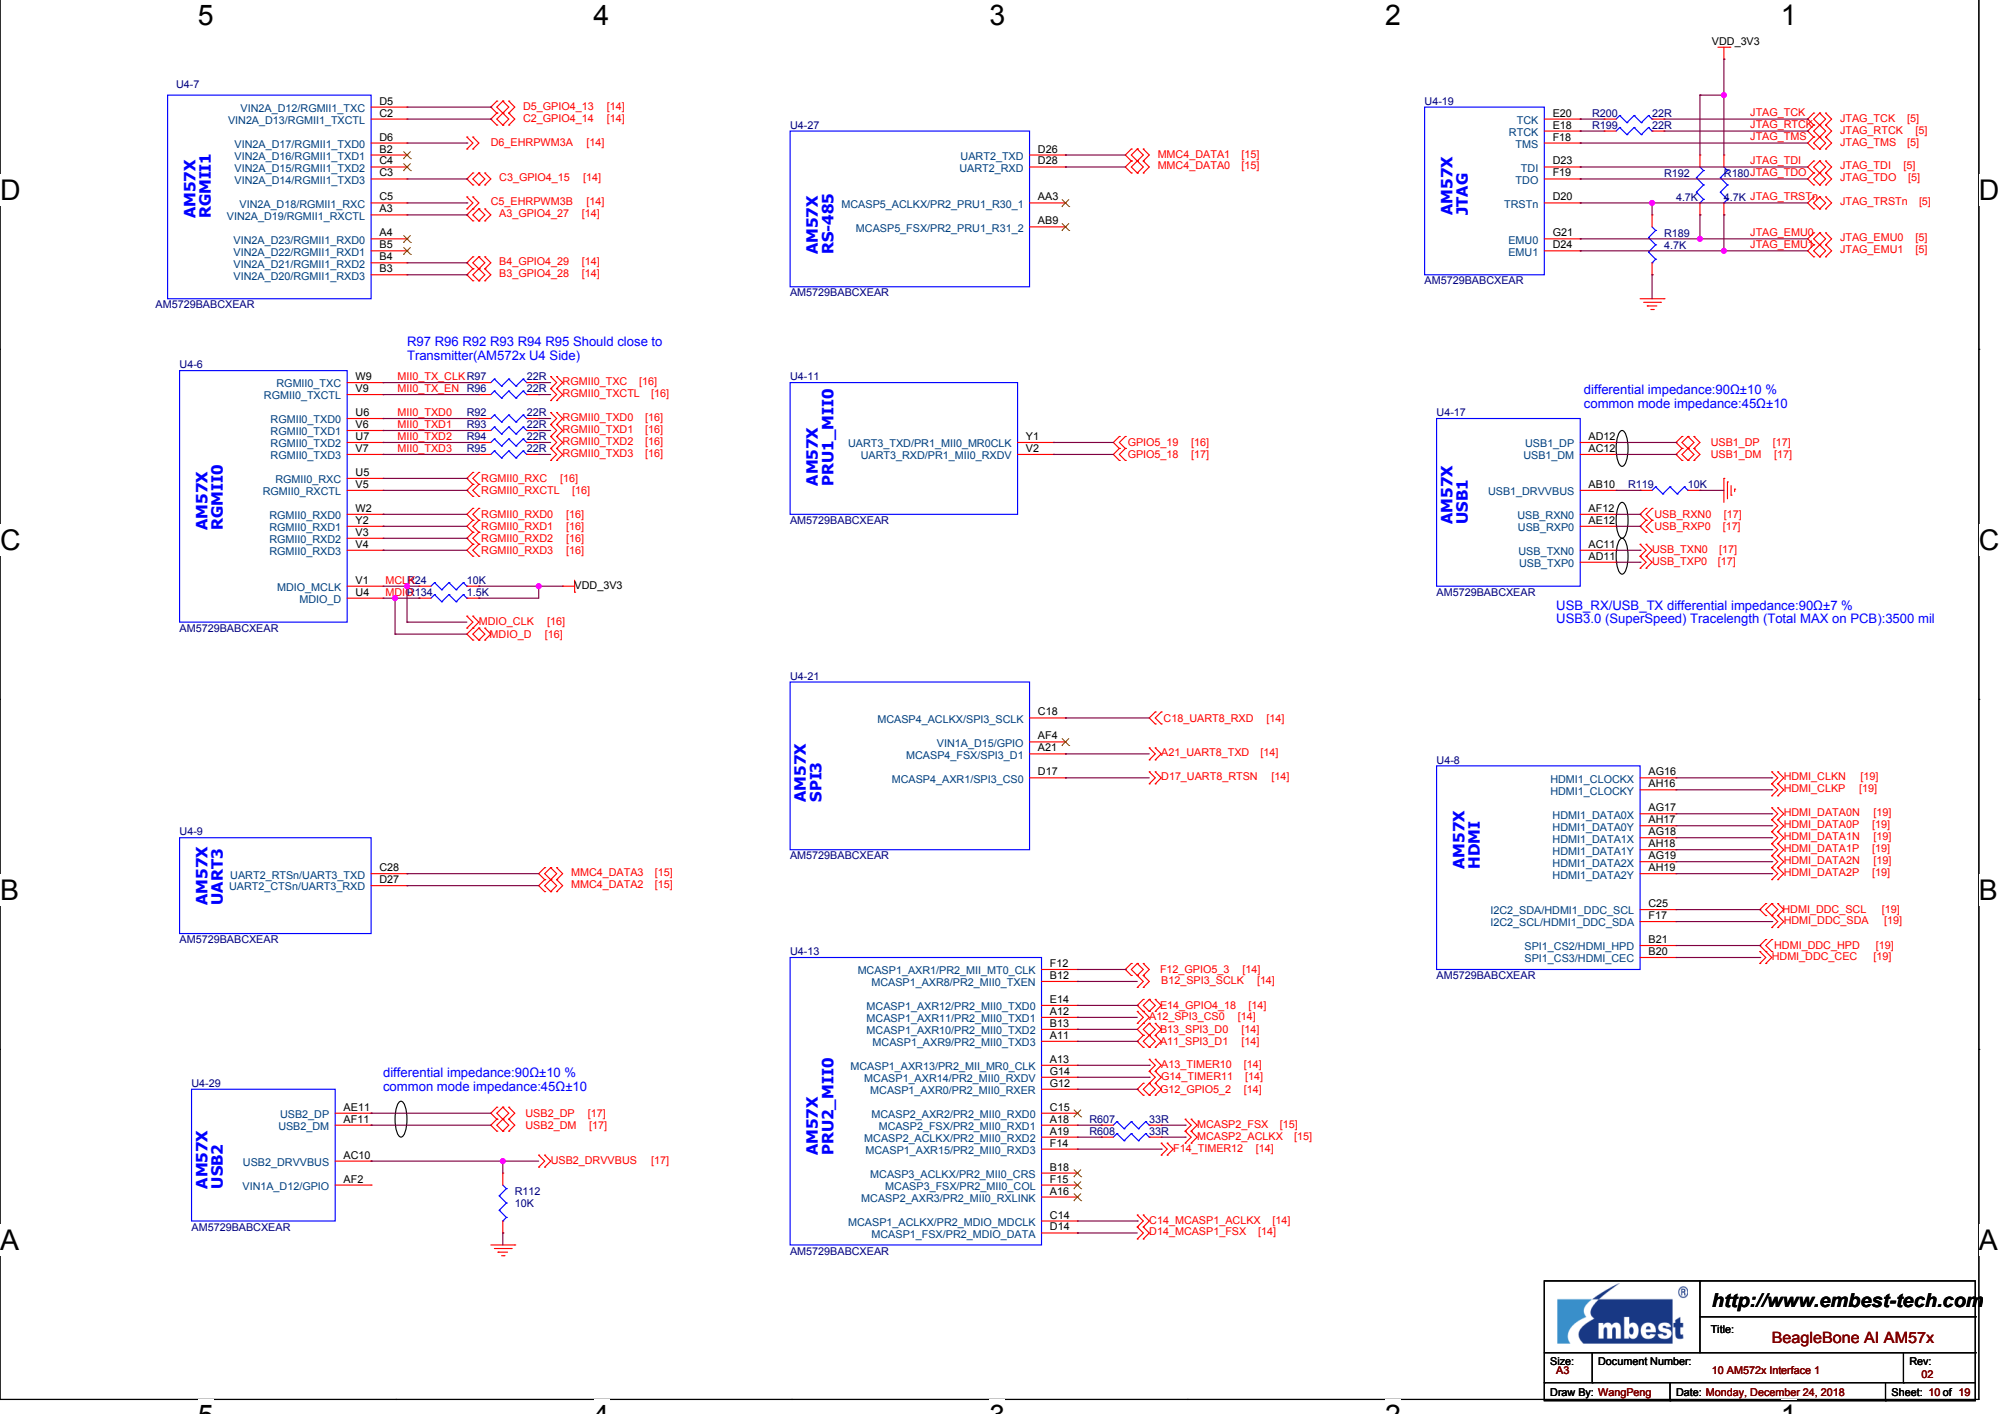
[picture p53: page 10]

USB_RX/USB_TX differential impedance:90Ω±7 %
USB3.0 (SuperSpeed) Tracelength (Total MAX on PCB):3500 mil

http://www.embest-tech.com

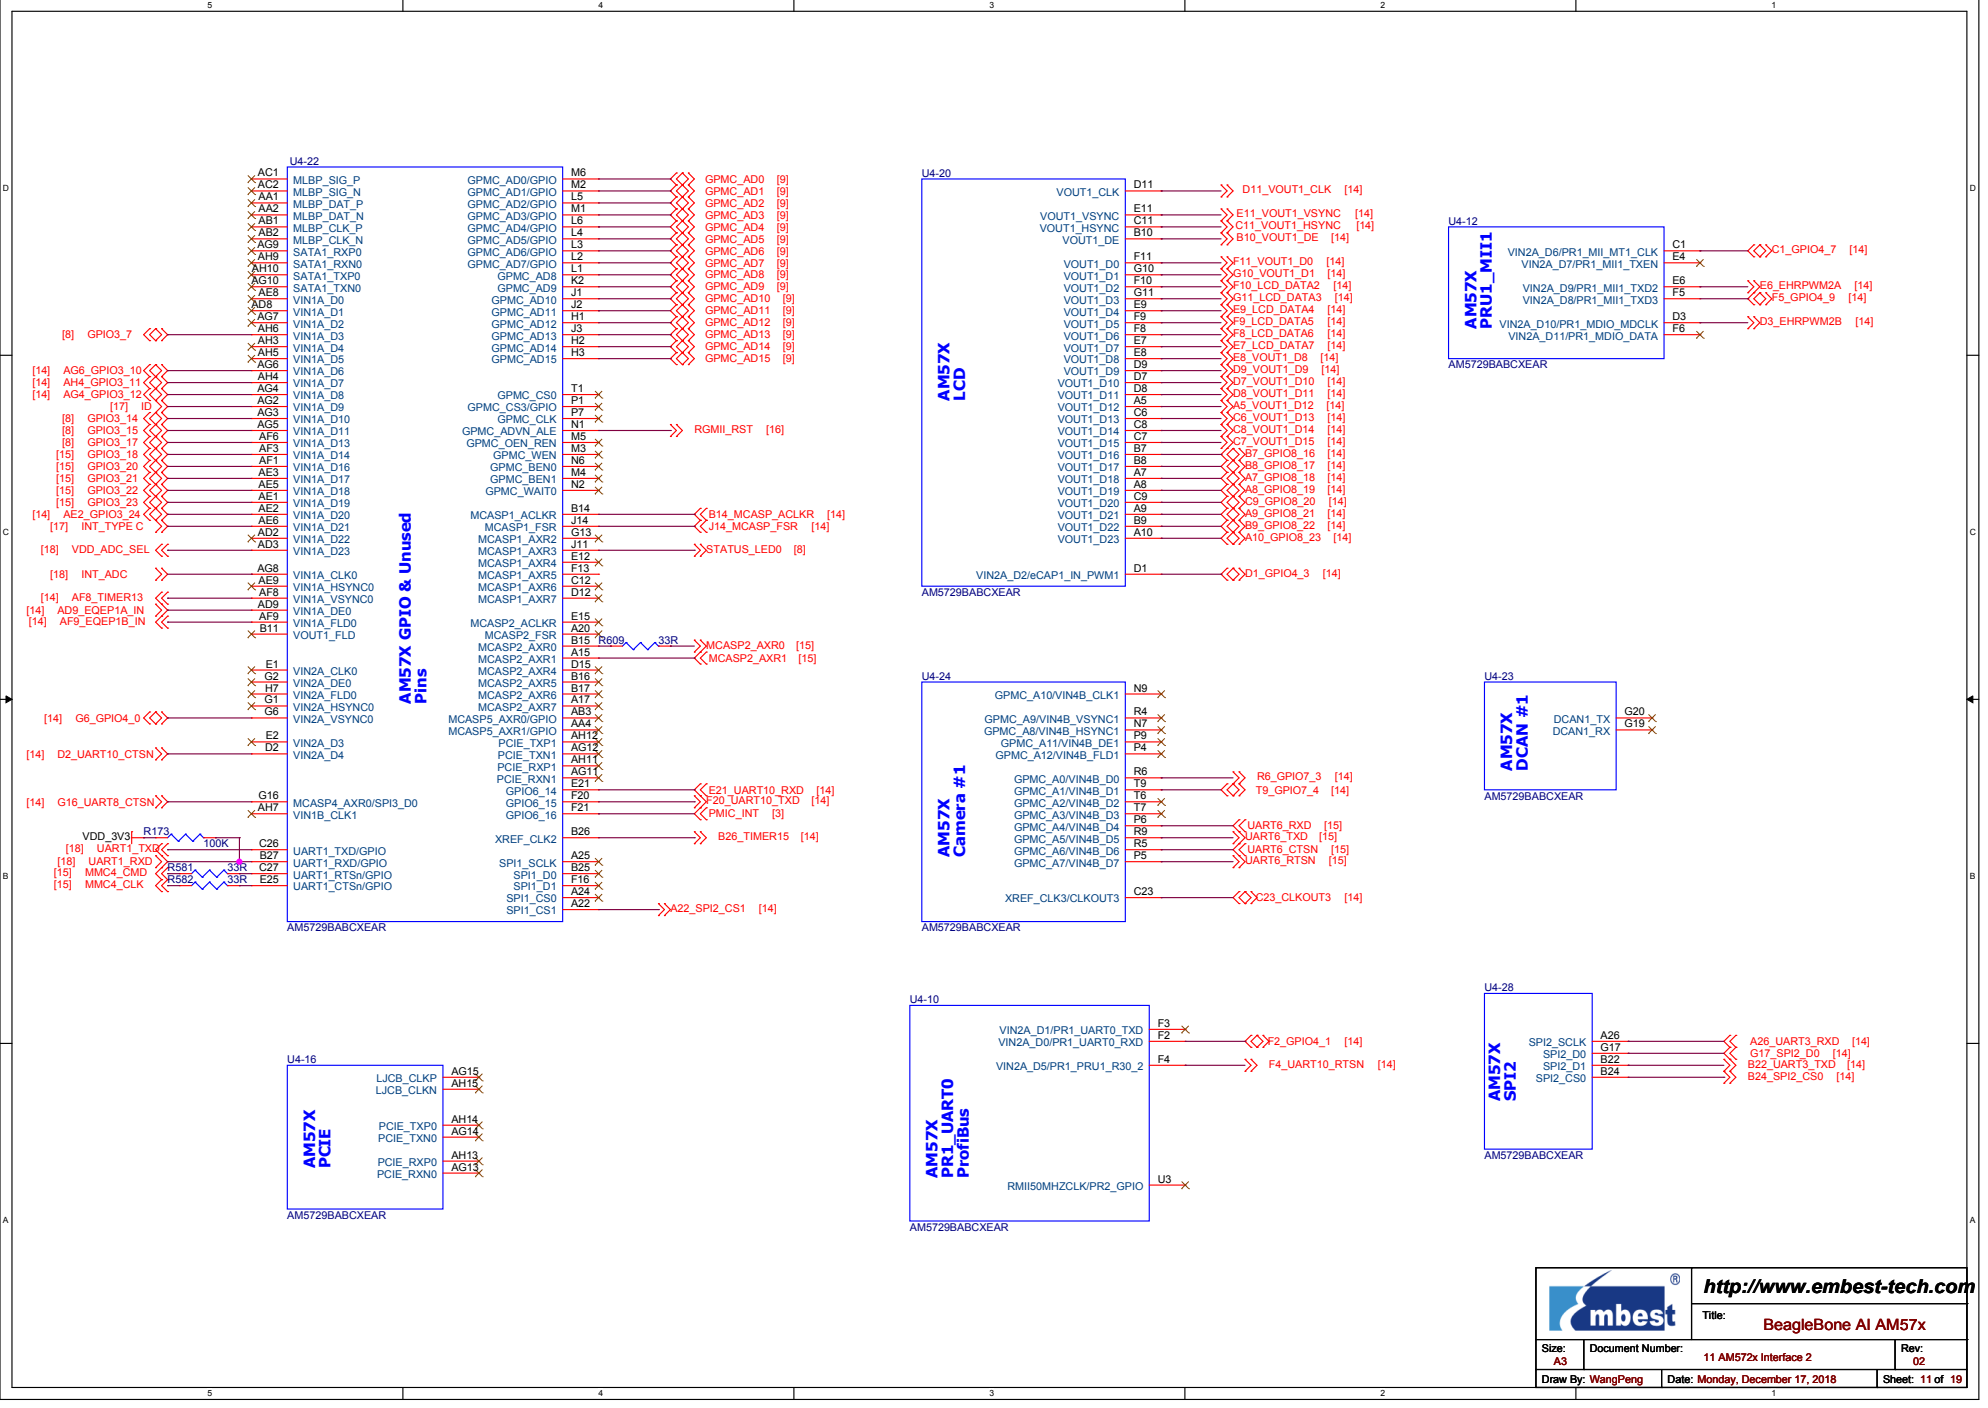
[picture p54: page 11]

http://www.embest-tech.com

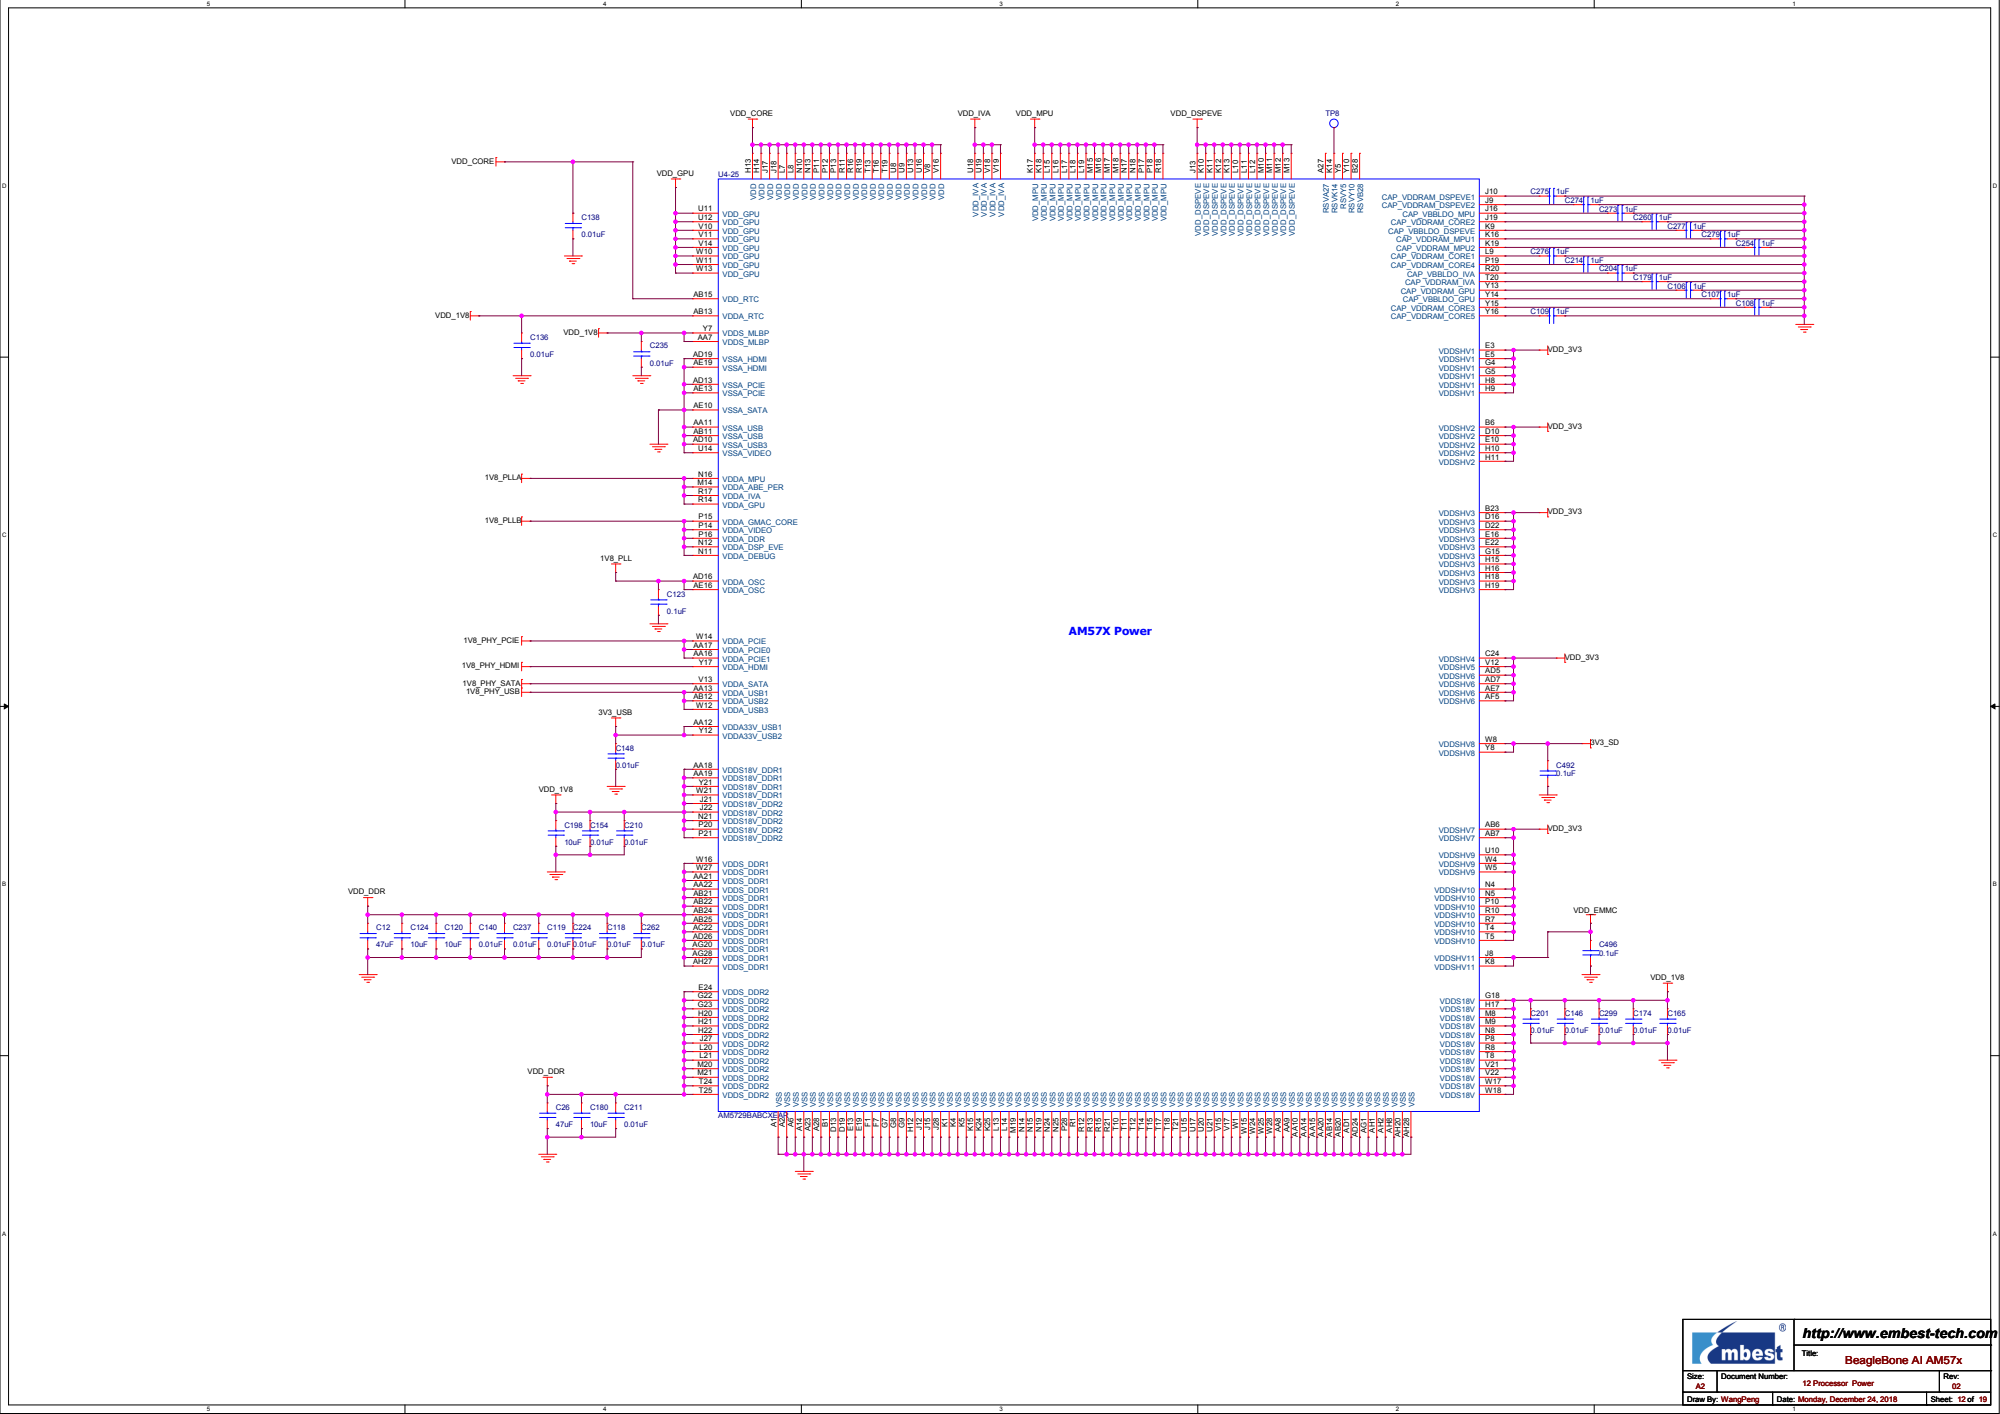
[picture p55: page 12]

http://www.embest-tech.com


http://www.embest-tech.com

# Exp Connect


http://www.embest-tech.com


http://www.embest-tech.com

# ETHERNET

### R458 R459 R460 R462 R464 R466 Should close to


http://www.embest-tech.com

### STUB on TypeC_D+ or TypeC_D-no greater than 3.5 mm


USB1_DP or DM pair differential impedance:90Ω±10 %
USB1_ DP or DM pair common mode impedance:45Ω±10

Place close to interface

USB 3.0 Layout Parameters:
USB_RX or TX pair differential impedance:90Ω±7 %
USB3.0 (SuperSpeed) Tracelength (Total MAX on PCB):3500 mil

All PCMF2USB30 place close to Interface

SSRX/SSTX differential impedance:90Ω±7 %

USB2_DP or DM pair differential impedance:90Ω±10 %
USB2_ DP or DM pair common mode impedance:45Ω±10

http://www.embest-tech.com

# ADC


http://www.embest-tech.com

## CMF+ESD


http://www.embest-tech.com


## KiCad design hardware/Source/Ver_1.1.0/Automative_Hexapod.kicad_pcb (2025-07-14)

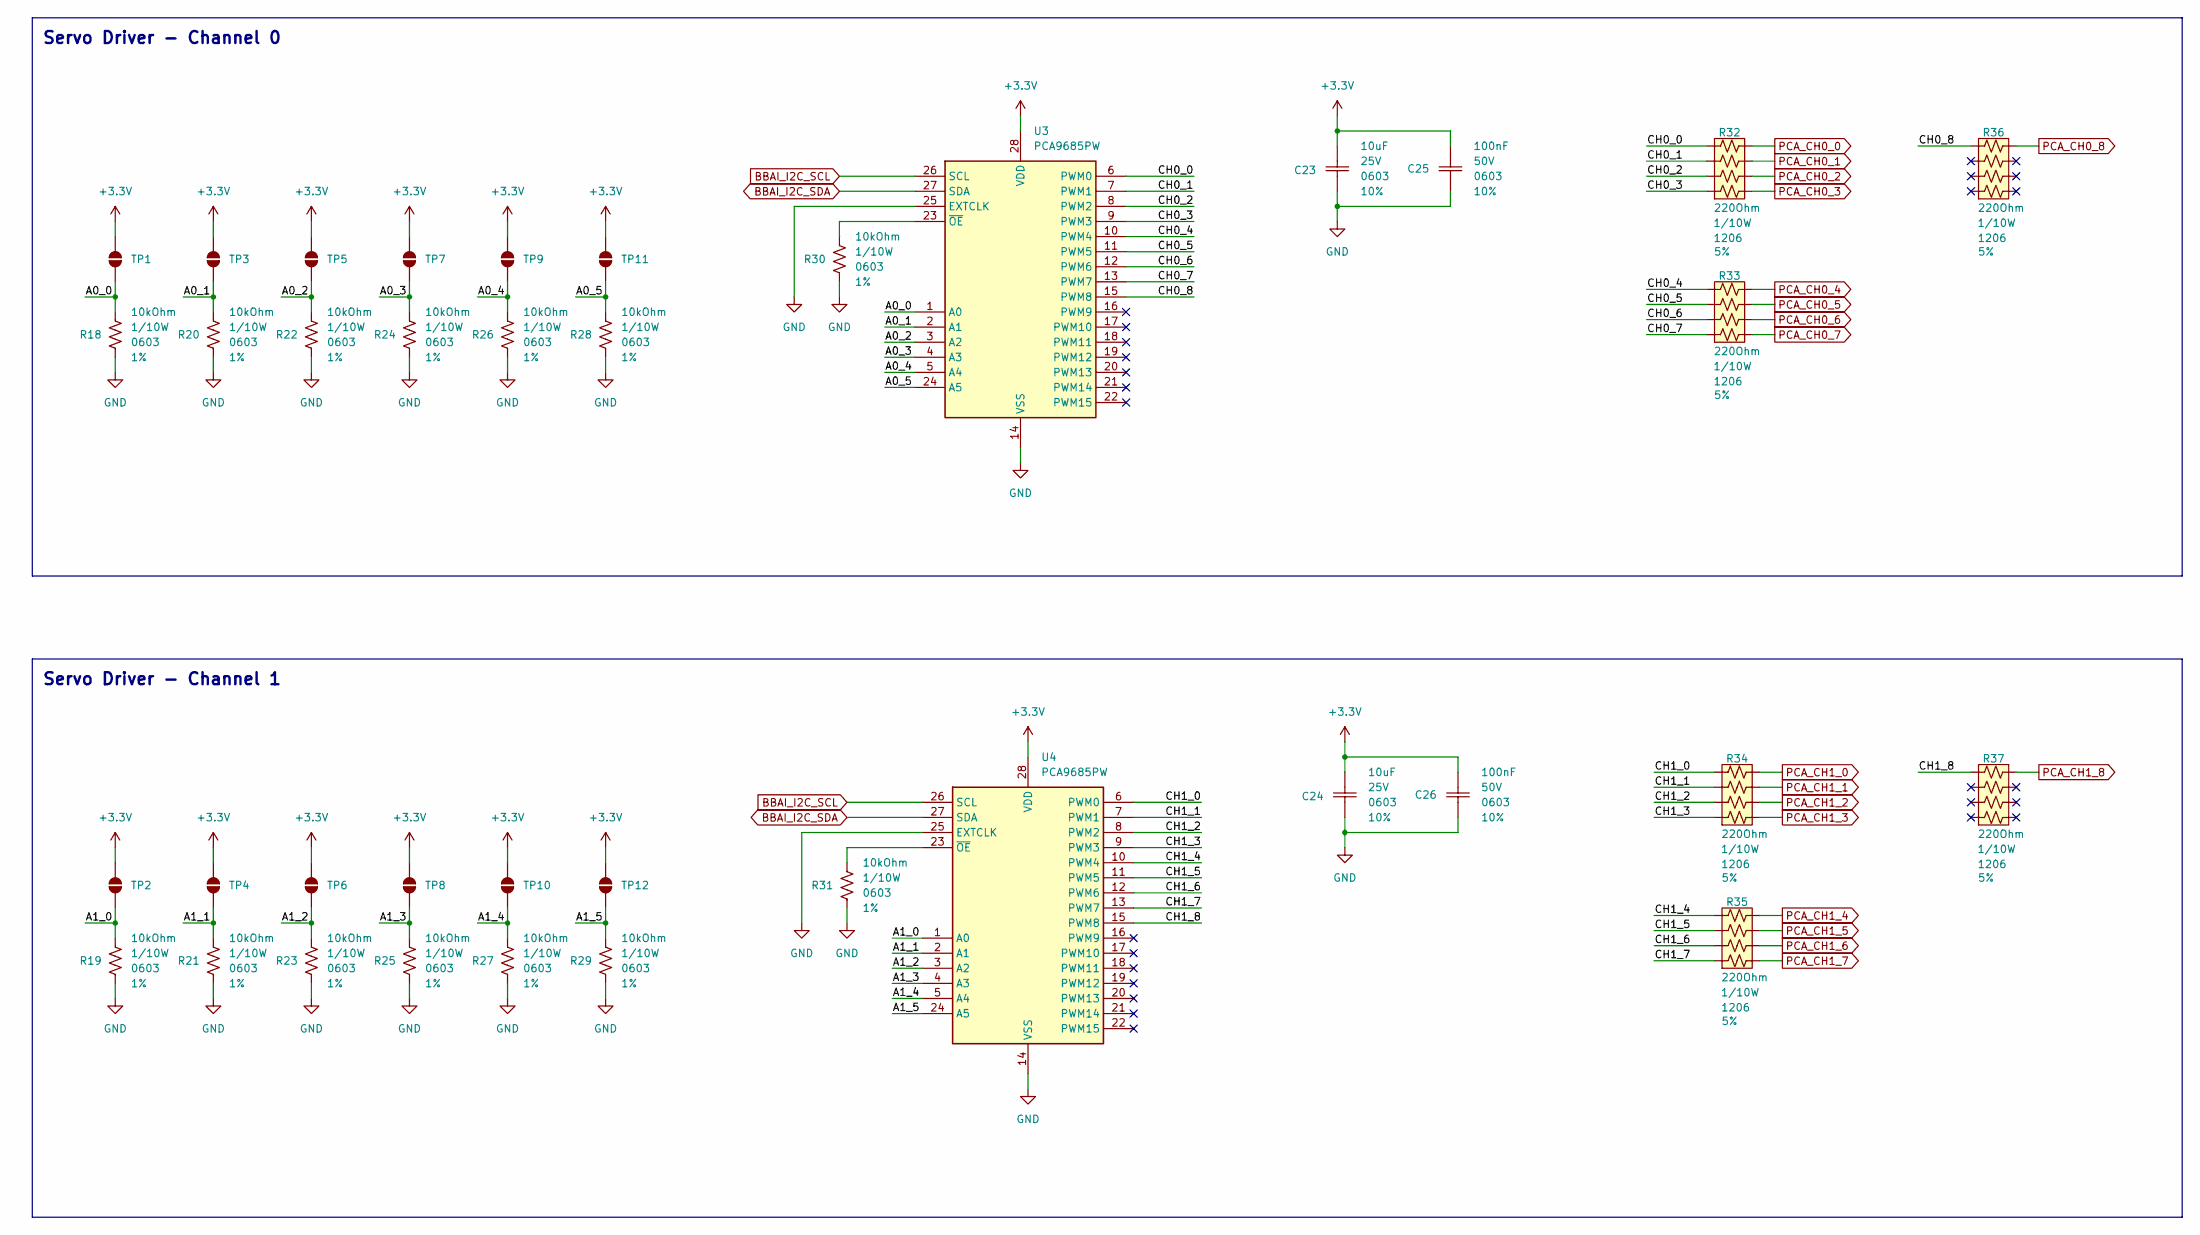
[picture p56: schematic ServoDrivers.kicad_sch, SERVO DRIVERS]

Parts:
C23, C24: 10uF; Ceramic_Cap_0603
C25, C26: 100nF; Ceramic_Cap_0603
R18, R19, R20, R21, R22, R23, R24, R25, R26, R27, R28, R29, R30, R31: 10kOhm; Res_0603
R32, R33, R34, R35, R36, R37: 220Ohm; R_Array_Convex_4x0603
TP1, TP2, TP3, TP4, TP5, TP6, TP7, TP8, TP9, TP10, TP11, TP12: SolderBridgeOpen
U3, U4: PCA9685PW; TSSOP-28_4.4x9.7mm_P0.65mm

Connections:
+3.3V: C23.2, C24.2, C25.2, C26.2, TP1.2, TP2.2, TP3.2, TP4.2, TP5.2, TP6.2, TP7.2, TP8.2, TP9.2, TP10.2, TP11.2, TP12.2, U3.28 (VDD), U4.28 (VDD); also elsewhere on the board
/Servo Drivers/A0_0: R18.2, TP1.1, U3.1 (A0)
/Servo Drivers/A0_1: R20.2, TP3.1, U3.2 (A1)
/Servo Drivers/A0_2: R22.2, TP5.1, U3.3 (A2)
/Servo Drivers/A0_3: R24.2, TP7.1, U3.4 (A3)
/Servo Drivers/A0_4: R26.2, TP9.1, U3.5 (A4)
/Servo Drivers/A0_5: R28.2, TP11.1, U3.24 (A5)
/Servo Drivers/A1_0: R19.2, TP2.1, U4.1 (A0)
/Servo Drivers/A1_1: R21.2, TP4.1, U4.2 (A1)
/Servo Drivers/A1_2: R23.2, TP6.1, U4.3 (A2)
/Servo Drivers/A1_3: R25.2, TP8.1, U4.4 (A3)
/Servo Drivers/A1_4: R27.2, TP10.1, U4.5 (A4)
/Servo Drivers/A1_5: R29.2, TP12.1, U4.24 (A5)
/Servo Drivers/CH0_0: R32.4, U3.6 (PWM0)
/Servo Drivers/CH0_1: R32.3, U3.7 (PWM1)
/Servo Drivers/CH0_2: R32.2, U3.8 (PWM2)
/Servo Drivers/CH0_3: R32.1, U3.9 (PWM3)
/Servo Drivers/CH0_4: R33.4, U3.10 (PWM4)
/Servo Drivers/CH0_5: R33.3, U3.11 (PWM5)
/Servo Drivers/CH0_6: R33.2, U3.12 (PWM6)
/Servo Drivers/CH0_7: R33.1, U3.13 (PWM7)
/Servo Drivers/CH0_8: R36.4, U3.15 (PWM8)
/Servo Drivers/CH1_0: R34.4, U4.6 (PWM0)
/Servo Drivers/CH1_1: R34.3, U4.7 (PWM1)
/Servo Drivers/CH1_2: R34.2, U4.8 (PWM2)
/Servo Drivers/CH1_3: R34.1, U4.9 (PWM3)
/Servo Drivers/CH1_4: R35.4, U4.10 (PWM4)
/Servo Drivers/CH1_5: R35.3, U4.11 (PWM5)
/Servo Drivers/CH1_6: R35.2, U4.12 (PWM6)
/Servo Drivers/CH1_7: R35.1, U4.13 (PWM7)
/Servo Drivers/CH1_8: R37.4, U4.15 (PWM8)
BBAI_I2C_SCL: U3.26 (SCL), U4.26 (SCL); also elsewhere on the board
BBAI_I2C_SDA: U3.27 (SDA), U4.27 (SDA); also elsewhere on the board
GND: C23.1, C24.1, C25.1, C26.1, R18.1, R19.1, R20.1, R21.1, R22.1, R23.1, R24.1, R25.1, R26.1, R27.1, R28.1, R29.1, R30.1, R31.1, U3.14 (VSS), U3.25 (EXTCLK), U4.14 (VSS), U4.25 (EXTCLK); also elsewhere on the board
unnamed: R30.2, U3.23 (~OE)
unnamed: R31.2, U4.23 (~OE)
PCA_CH0_0: R32.5; also elsewhere on the board
PCA_CH0_1: R32.6; also elsewhere on the board
PCA_CH0_2: R32.7; also elsewhere on the board
PCA_CH0_3: R32.8; also elsewhere on the board
PCA_CH0_4: R33.5; also elsewhere on the board
PCA_CH0_5: R33.6; also elsewhere on the board
PCA_CH0_6: R33.7; also elsewhere on the board
PCA_CH0_7: R33.8; also elsewhere on the board
PCA_CH0_8: R36.5; also elsewhere on the board
PCA_CH1_0: R34.5; also elsewhere on the board
PCA_CH1_1: R34.6; also elsewhere on the board
PCA_CH1_2: R34.7; also elsewhere on the board
PCA_CH1_3: R34.8; also elsewhere on the board
PCA_CH1_4: R35.5; also elsewhere on the board
PCA_CH1_5: R35.6; also elsewhere on the board
PCA_CH1_6: R35.7; also elsewhere on the board
PCA_CH1_7: R35.8; also elsewhere on the board
PCA_CH1_8: R37.5; also elsewhere on the board

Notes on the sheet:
Servo Driver - Channel 1
Servo Driver - Channel 0

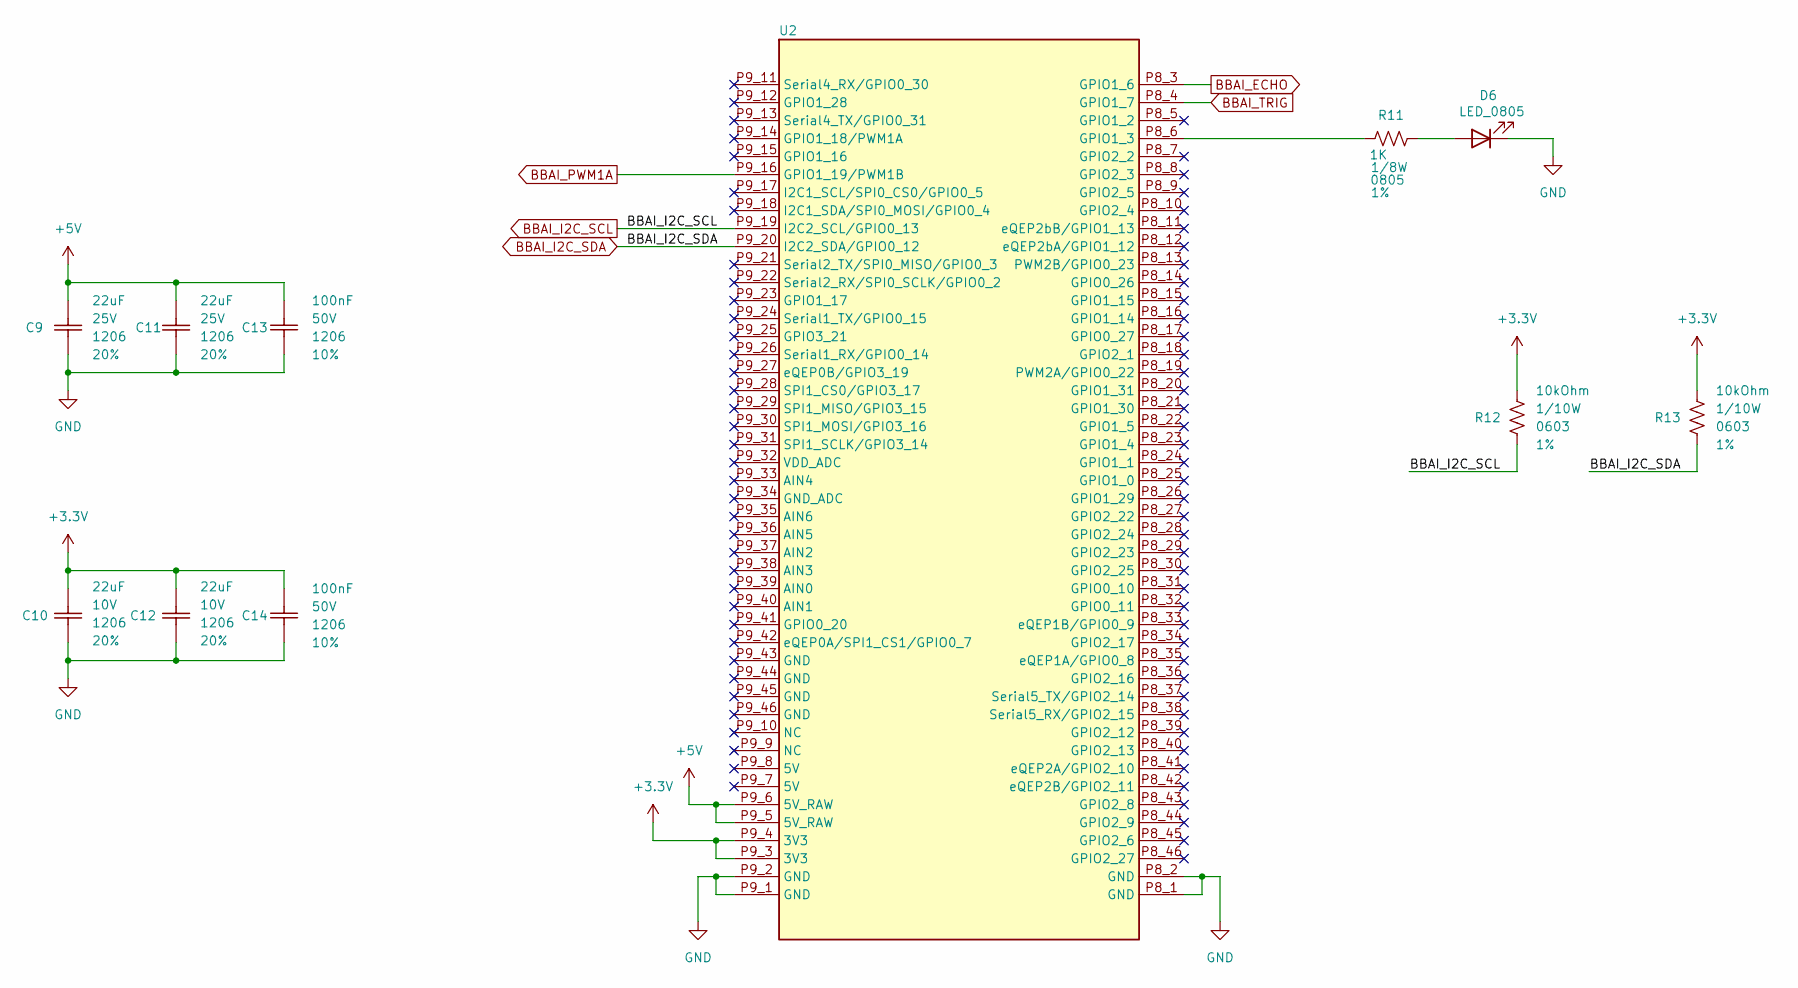
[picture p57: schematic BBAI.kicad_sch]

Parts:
C9, C10, C11, C12: 22uF; Ceramic_Cap_1206
C13, C14: 100nF; Ceramic_Cap_1206
D6: LED_0805
R11: 1K; Res_0805
R12, R13: 10kOhm; Res_0603
U2: BeagleBone_AI

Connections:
+3.3V: C10.2, C12.2, C14.1, R12.2, R13.2, U2.P9_3 (3V3), U2.P9_4 (3V3); also elsewhere on the board
+5V: C9.2, C11.2, C13.1, U2.P9_5 (5V_RAW), U2.P9_6 (5V_RAW); also elsewhere on the board
BBAI_ECHO: U2.P8_3 (GPIO1_6); also elsewhere on the board
BBAI_I2C_SCL: R12.1, U2.P9_19 (I2C2_SCL/GPIO0_13); also elsewhere on the board
BBAI_I2C_SDA: R13.1, U2.P9_20 (I2C2_SDA/GPIO0_12); also elsewhere on the board
BBAI_PWM1A: U2.P9_16 (GPIO1_19/PWM1B); also elsewhere on the board
BBAI_TRIG: U2.P8_4 (GPIO1_7); also elsewhere on the board
GND: C9.1, C10.1, C11.1, C12.1, C13.2, C14.2, D6.1 (K), U2.P8_1 (GND), U2.P8_2 (GND), U2.P9_1 (GND), U2.P9_2 (GND); also elsewhere on the board
unnamed: D6.2 (A), R11.2
unnamed: R11.1, U2.P8_6 (GPIO1_3)

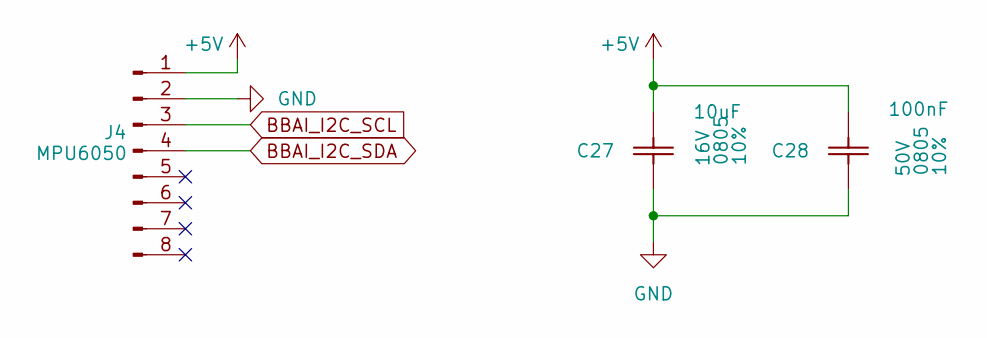
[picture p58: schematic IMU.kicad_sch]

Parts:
C27: 10uF; Ceramic_Cap_0805
C28: 100nF; Ceramic_Cap_0805
J4: MPU6050

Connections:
+5V: C27.2, C28.2, J4.1; also elsewhere on the board
BBAI_I2C_SCL: J4.3; also elsewhere on the board
BBAI_I2C_SDA: J4.4; also elsewhere on the board
GND: C27.1, C28.1, J4.2; also elsewhere on the board

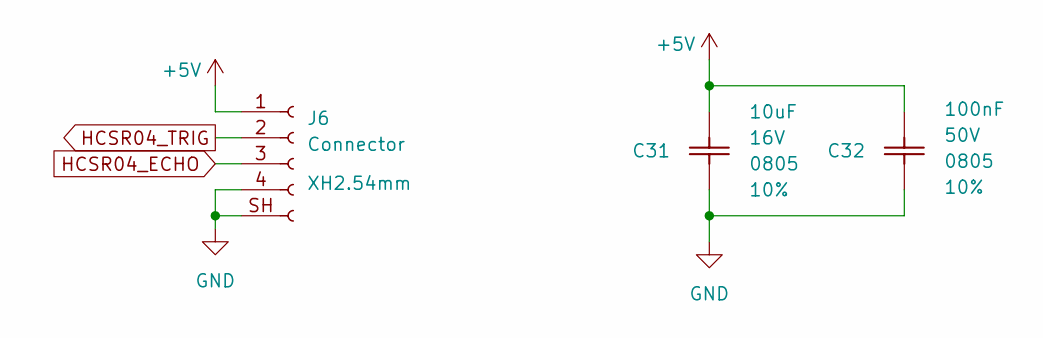
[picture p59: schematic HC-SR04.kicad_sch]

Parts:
C31: 10uF; Ceramic_Cap_0805
C32: 100nF; Ceramic_Cap_0805
J6: Connector; JST-XH-SMD-4-2.54mm

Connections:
+5V: C31.2, C32.2, J6.1; also elsewhere on the board
GND: C31.1, C32.1, J6.4, J6.SH (Pin_3); also elsewhere on the board
HCSR04_ECHO: J6.3; also elsewhere on the board
HCSR04_TRIG: J6.2; also elsewhere on the board

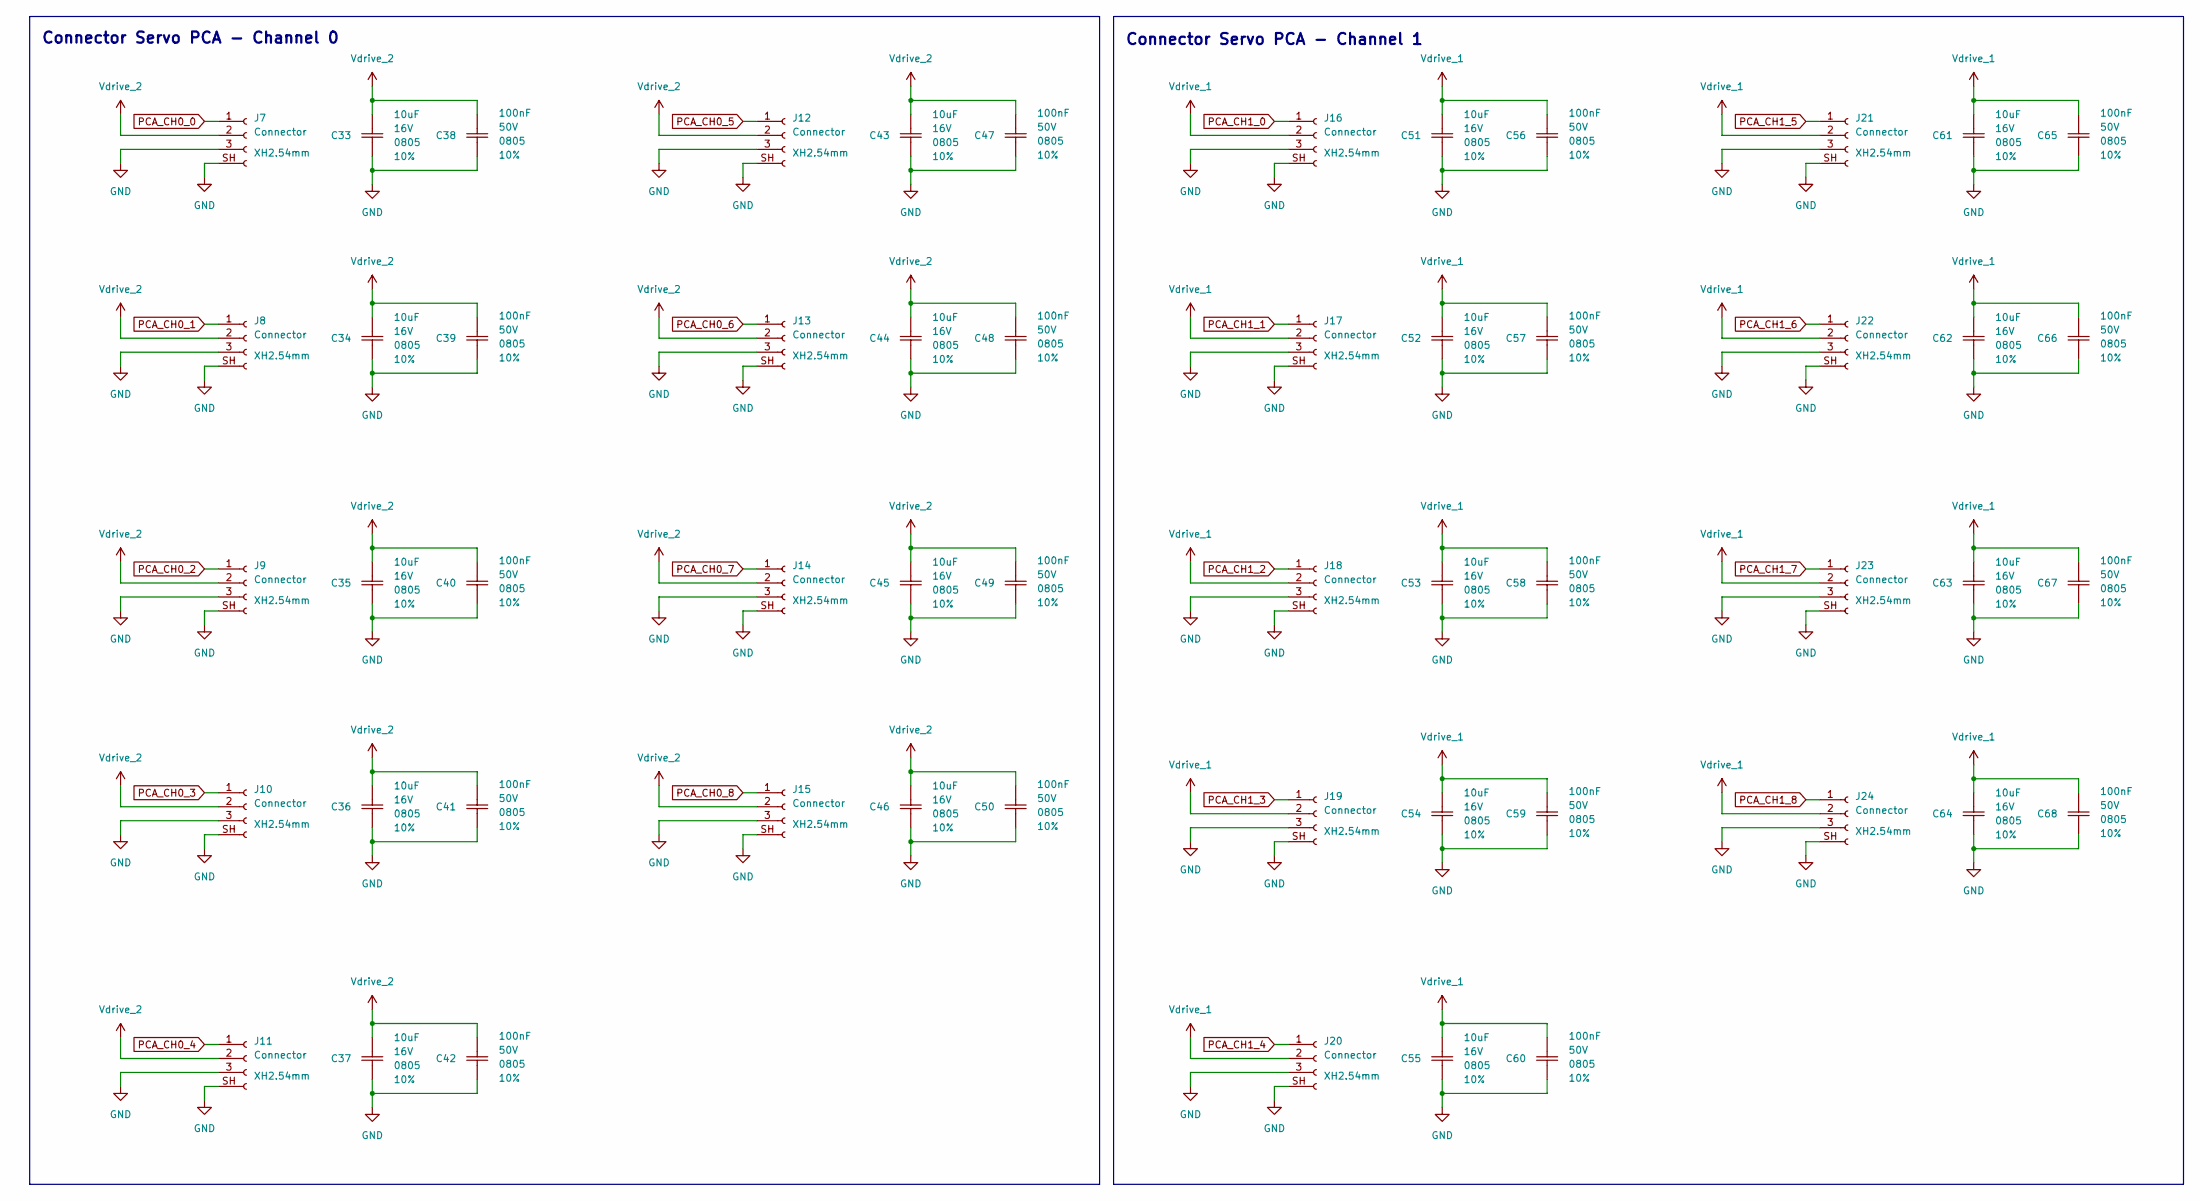
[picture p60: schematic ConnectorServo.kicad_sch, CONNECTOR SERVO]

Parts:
C33, C34, C35, C36, C37, C43, C44, C45, C46, C51, C52, C53, C54, C55, C61, C62, C63, C64: 10uF; Ceramic_Cap_0805
C38, C39, C40, C41, C42, C47, C48, C49, C50, C56, C57, C58, C59, C60, C65, C66, C67, C68: 100nF; Ceramic_Cap_0805
J7, J8, J9, J10, J11, J12, J13, J14, J15, J16, J17, J18, J19, J20, J21, J22, J23, J24: Connector; JST-XH-SMD-3-2.54mm

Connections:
GND: C33.1, C34.1, C35.1, C36.1, C37.1, C38.1, C39.1, C40.1, C41.1, C42.1, C43.1, C44.1, C45.1, C46.1, C47.1, C48.1, C49.1, C50.1, C51.1, C52.1, C53.1, C54.1, C55.1, C56.1, C57.1, C58.1, C59.1, C60.1, C61.1, C62.1, C63.1, C64.1, C65.1, C66.1, C67.1, C68.1, J7.3, J7.SH (Pin_3), J8.3, J8.SH (Pin_3), J9.3, J9.SH (Pin_3), J10.3, J10.SH (Pin_3), J11.3, J11.SH (Pin_3), J12.3, J12.SH (Pin_3), J13.3, J13.SH (Pin_3), J14.3, J14.SH (Pin_3), J15.3, J15.SH (Pin_3), J16.3, J16.SH (Pin_3), J17.3, J17.SH (Pin_3), J18.3, J18.SH (Pin_3), J19.3, J19.SH (Pin_3), J20.3, J20.SH (Pin_3), J21.3, J21.SH (Pin_3), J22.3, J22.SH (Pin_3), J23.3, J23.SH (Pin_3), J24.3, J24.SH (Pin_3); also elsewhere on the board
PCA_CH0_0: J7.1; also elsewhere on the board
PCA_CH0_1: J8.1; also elsewhere on the board
PCA_CH0_2: J9.1; also elsewhere on the board
PCA_CH0_3: J10.1; also elsewhere on the board
PCA_CH0_4: J11.1; also elsewhere on the board
PCA_CH0_5: J12.1; also elsewhere on the board
PCA_CH0_6: J13.1; also elsewhere on the board
PCA_CH0_7: J14.1; also elsewhere on the board
PCA_CH0_8: J15.1; also elsewhere on the board
PCA_CH1_0: J16.1; also elsewhere on the board
PCA_CH1_1: J17.1; also elsewhere on the board
PCA_CH1_2: J18.1; also elsewhere on the board
PCA_CH1_3: J19.1; also elsewhere on the board
PCA_CH1_4: J20.1; also elsewhere on the board
PCA_CH1_5: J21.1; also elsewhere on the board
PCA_CH1_6: J22.1; also elsewhere on the board
PCA_CH1_7: J23.1; also elsewhere on the board
PCA_CH1_8: J24.1; also elsewhere on the board
Vdrive_1: C51.2, C52.2, C53.2, C54.2, C55.2, C56.2, C57.2, C58.2, C59.2, C60.2, C61.2, C62.2, C63.2, C64.2, C65.2, C66.2, C67.2, C68.2, J16.2, J17.2, J18.2, J19.2, J20.2, J21.2, J22.2, J23.2, J24.2; also elsewhere on the board
Vdrive_2: C33.2, C34.2, C35.2, C36.2, C37.2, C38.2, C39.2, C40.2, C41.2, C42.2, C43.2, C44.2, C45.2, C46.2, C47.2, C48.2, C49.2, C50.2, J7.2, J8.2, J9.2, J10.2, J11.2, J12.2, J13.2, J14.2, J15.2; also elsewhere on the board

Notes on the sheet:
Connector Servo PCA - Channel 0
Connector Servo PCA - Channel 1

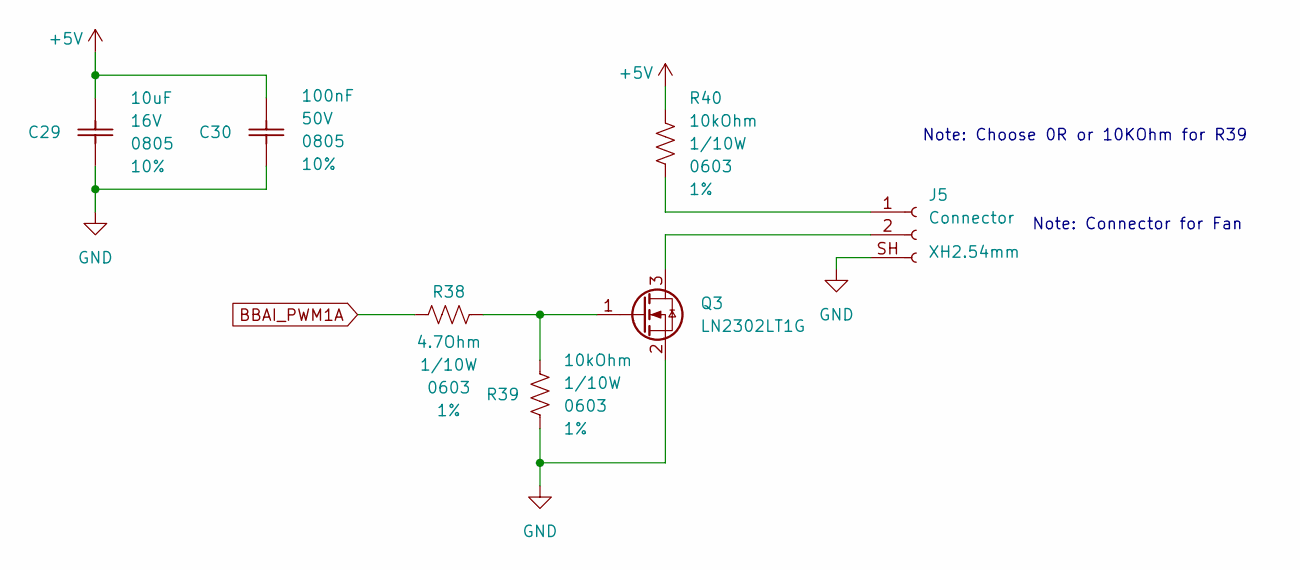
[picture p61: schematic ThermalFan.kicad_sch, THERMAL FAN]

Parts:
C29: 10uF; Ceramic_Cap_0805
C30: 100nF; Ceramic_Cap_0805
J5: Connector; JST-XH-SMD-2-2.54mm
Q3: LN2302LT1G; SOT23
R38: 4.7Ohm; Res_0603
R39, R40: 10kOhm; Res_0603

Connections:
+5V: C29.2, C30.2, R40.2; also elsewhere on the board
BBAI_PWM1A: R38.1; also elsewhere on the board
GND: C29.1, C30.1, J5.SH (Pin_3), Q3.2 (S), R39.1; also elsewhere on the board
unnamed: J5.1, R40.1
unnamed: J5.2, Q3.3 (D)
unnamed: Q3.1 (G), R38.2, R39.2

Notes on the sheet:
Note: Connector for Fan
Note: Choose 0R or 10KOhm for R39

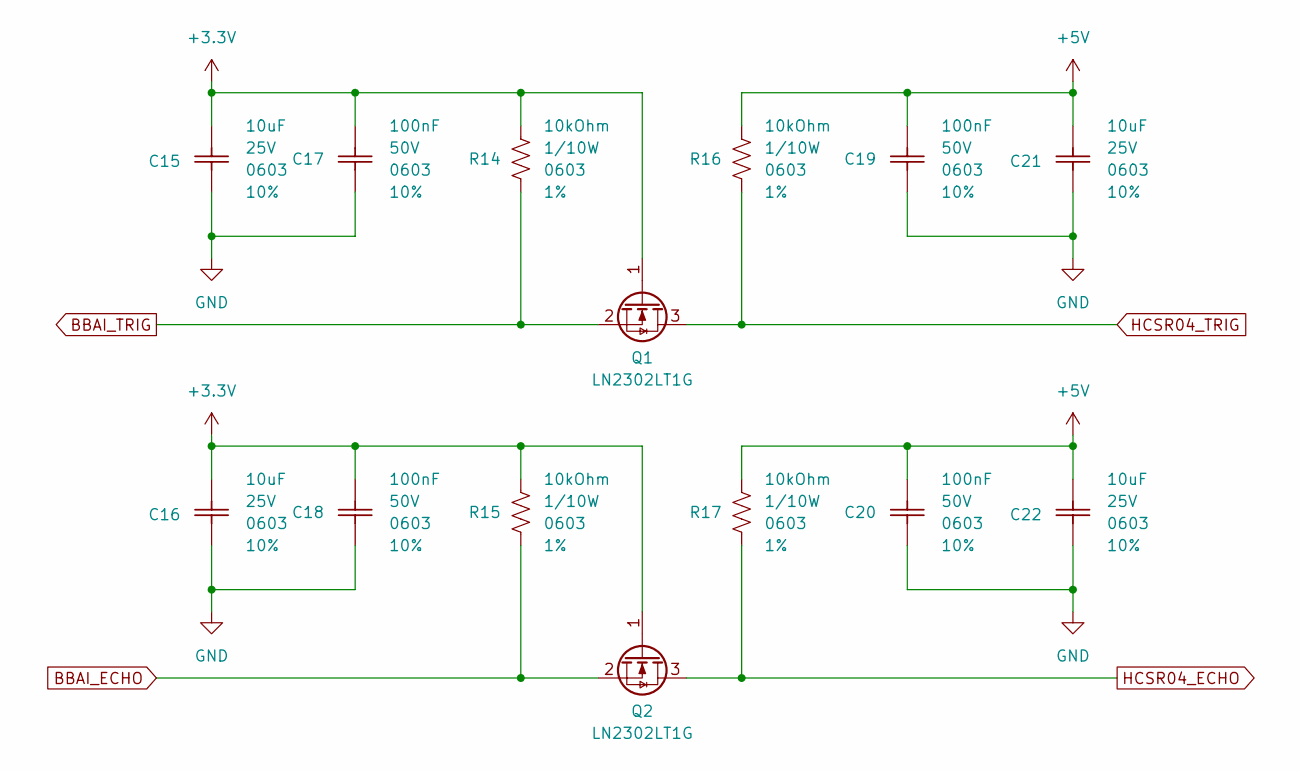
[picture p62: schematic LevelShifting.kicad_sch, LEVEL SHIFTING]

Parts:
C15, C16, C21, C22: 10uF; Ceramic_Cap_0603
C17, C18, C19, C20: 100nF; Ceramic_Cap_0603
Q1, Q2: LN2302LT1G; SOT23
R14, R15, R16, R17: 10kOhm; Res_0603

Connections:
+3.3V: C15.2, C16.2, C17.2, C18.2, Q1.1 (G), Q2.1 (G), R14.2, R15.2; also elsewhere on the board
+5V: C19.2, C20.2, C21.2, C22.2, R16.2, R17.2; also elsewhere on the board
BBAI_ECHO: Q2.2 (S), R15.1; also elsewhere on the board
BBAI_TRIG: Q1.2 (S), R14.1; also elsewhere on the board
GND: C15.1, C16.1, C17.1, C18.1, C19.1, C20.1, C21.1, C22.1; also elsewhere on the board
HCSR04_ECHO: Q2.3 (D), R17.1; also elsewhere on the board
HCSR04_TRIG: Q1.3 (D), R16.1; also elsewhere on the board

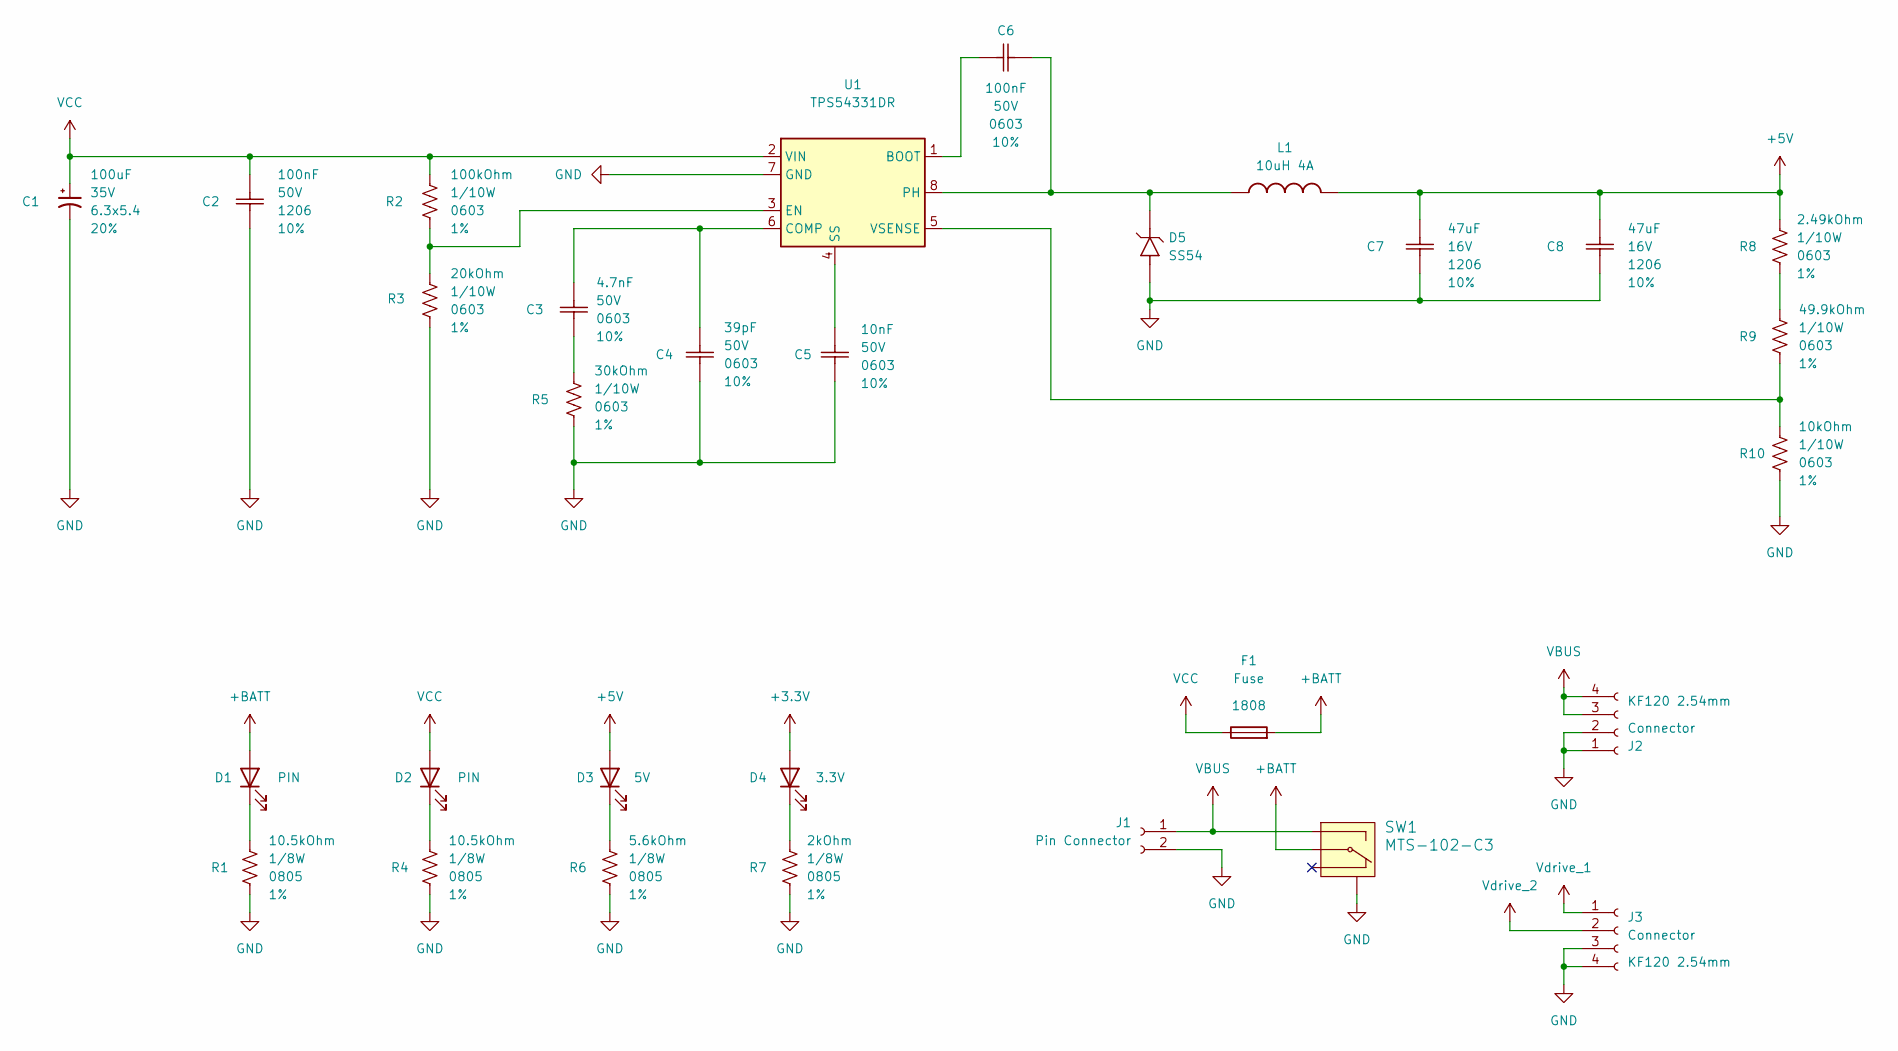
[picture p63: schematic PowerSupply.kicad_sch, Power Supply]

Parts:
C1: 100uF; CP_Elec_6.3x5.4
C2: 100nF; Ceramic_Cap_1206
C3: 4.7nF; Ceramic_Cap_0603
C4: 39pF; Ceramic_Cap_0603
C5: 10nF; Ceramic_Cap_0603
C6: 100nF; Ceramic_Cap_0603
C7, C8: 47uF; Ceramic_Cap_1206
D1, D2: PIN; LED_0805
D3: 5V; LED_0805
D4: 3.3V; LED_0805
D5: SS54; D_SMA
F1: Fuse; FUSE_SMD_1808
J1: Pin Connector; Connector-Pin
J2, J3: Connector; TerminalBlock_Phoenix_MKDS-1,5-4-5.08_1x04_P5.08mm_Horizont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
L1: 10uH 4A; Inductor_0630
R1, R4: 10.5kOhm; Res_0805
R2: 100kOhm; Res_0603
R3: 20kOhm; Res_0603
R5: 30kOhm; Res_0603
R6: 5.6kOhm; Res_0805
R7: 2kOhm; Res_0805
R8: 2.49kOhm; Res_0603
R9: 49.9kOhm; Res_0603
R10: 10kOhm; Res_0603
SW1: MTS-102-C3
U1: TPS54331DR; SOIC-8

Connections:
+3.3V: D4.2 (A); also elsewhere on the board
+5V: C7.2, C8.2, D3.2 (A), L1.2, R8.2; also elsewhere on the board
+BATT: D1.2 (A), F1.2, SW1.2
GND: C1.2, C2.2, C4.1, C5.1, C7.1, C8.1, D5.1 (A), J1.2, J2.1, J2.2, J3.3, J3.4, R1.1, R3.1, R4.1, R5.1, R6.1, R7.1, R10.1, SW1.SH, U1.7 (GND); also elsewhere on the board
unnamed: C3.1, R5.2
unnamed: D1.1 (K), R1.2
unnamed: D2.1 (K), R4.2
unnamed: D3.1 (K), R6.2
unnamed: D4.1 (K), R7.2
unnamed: C6.2, D5.2 (K), L1.1, U1.8 (PH)
unnamed: R8.1, R9.2
unnamed: C6.1, U1.1 (BOOT)
unnamed: C3.2, C4.2, U1.6 (COMP)
unnamed: R2.1, R3.2, U1.3 (EN)
unnamed: C5.2, U1.4 (SS)
unnamed: R9.1, R10.2, U1.5 (VSENSE)
VBUS: J1.1, J2.3, J2.4, SW1.3
VCC: C1.1, C2.1, D2.2 (A), F1.1, R2.2, U1.2 (VIN)
Vdrive_1: J3.1; also elsewhere on the board
Vdrive_2: J3.2; also elsewhere on the board

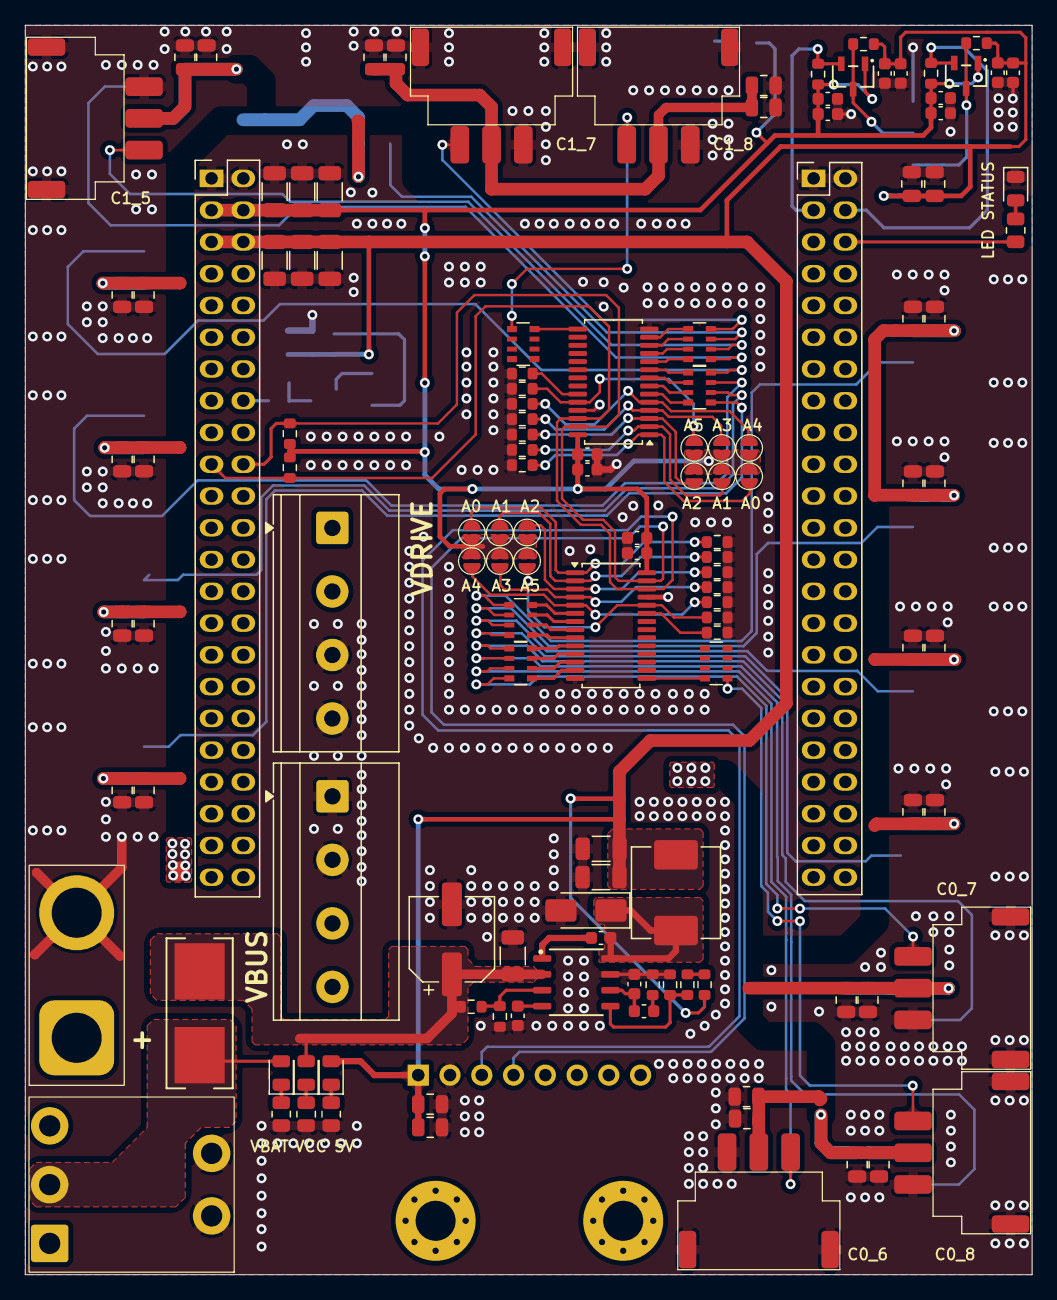
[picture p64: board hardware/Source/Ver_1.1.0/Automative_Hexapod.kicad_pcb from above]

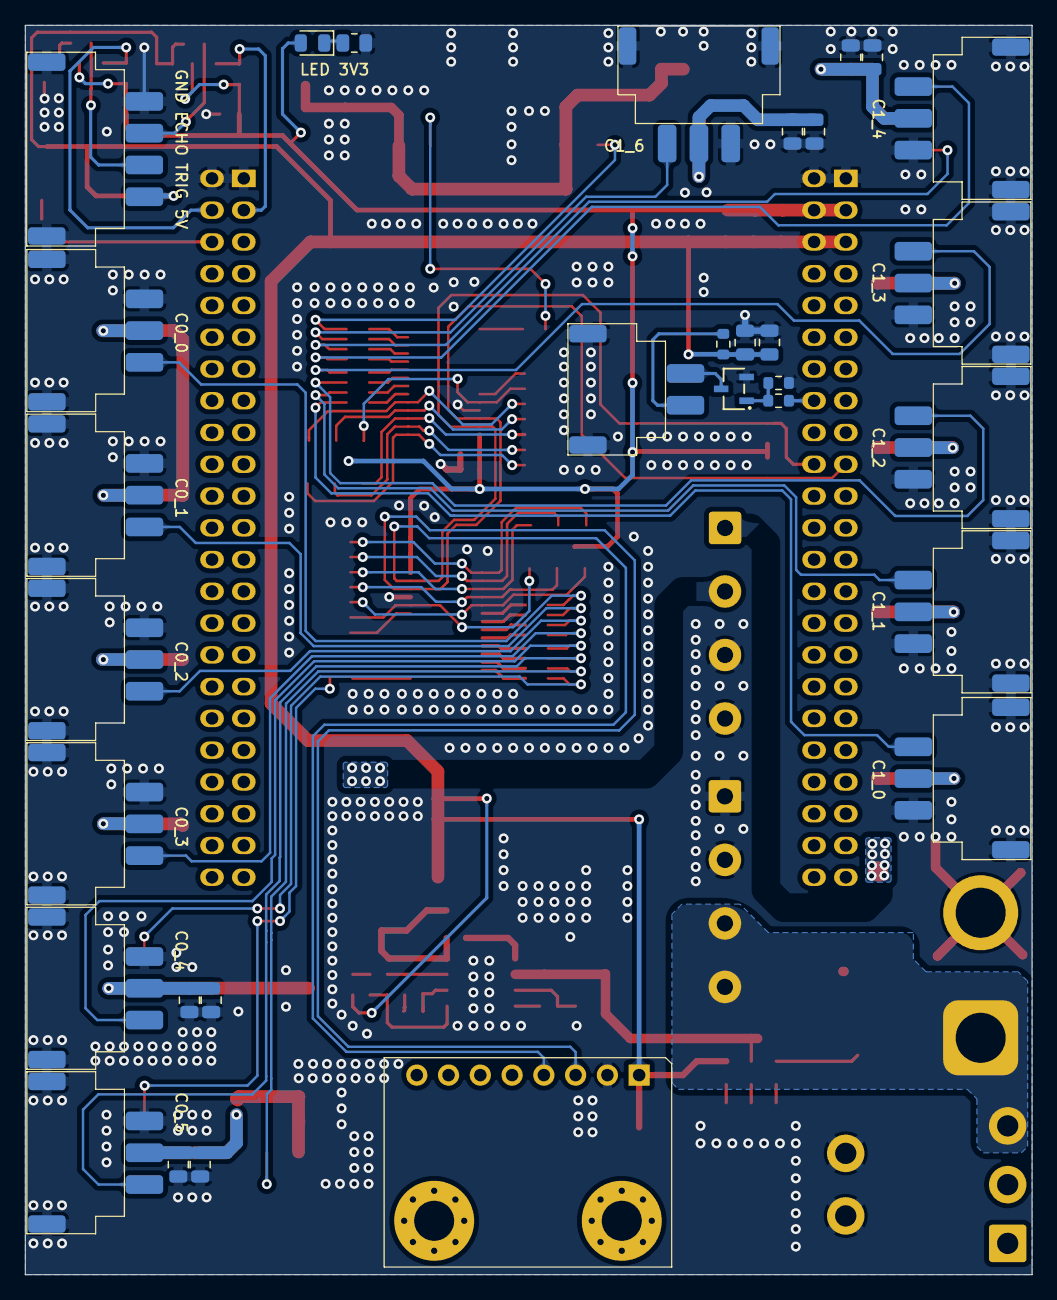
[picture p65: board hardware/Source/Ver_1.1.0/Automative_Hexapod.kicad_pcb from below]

Board: 2 copper layers, 80.5 x 99.9 mm, 160 parts (31 on the bottom side), 82 nets.

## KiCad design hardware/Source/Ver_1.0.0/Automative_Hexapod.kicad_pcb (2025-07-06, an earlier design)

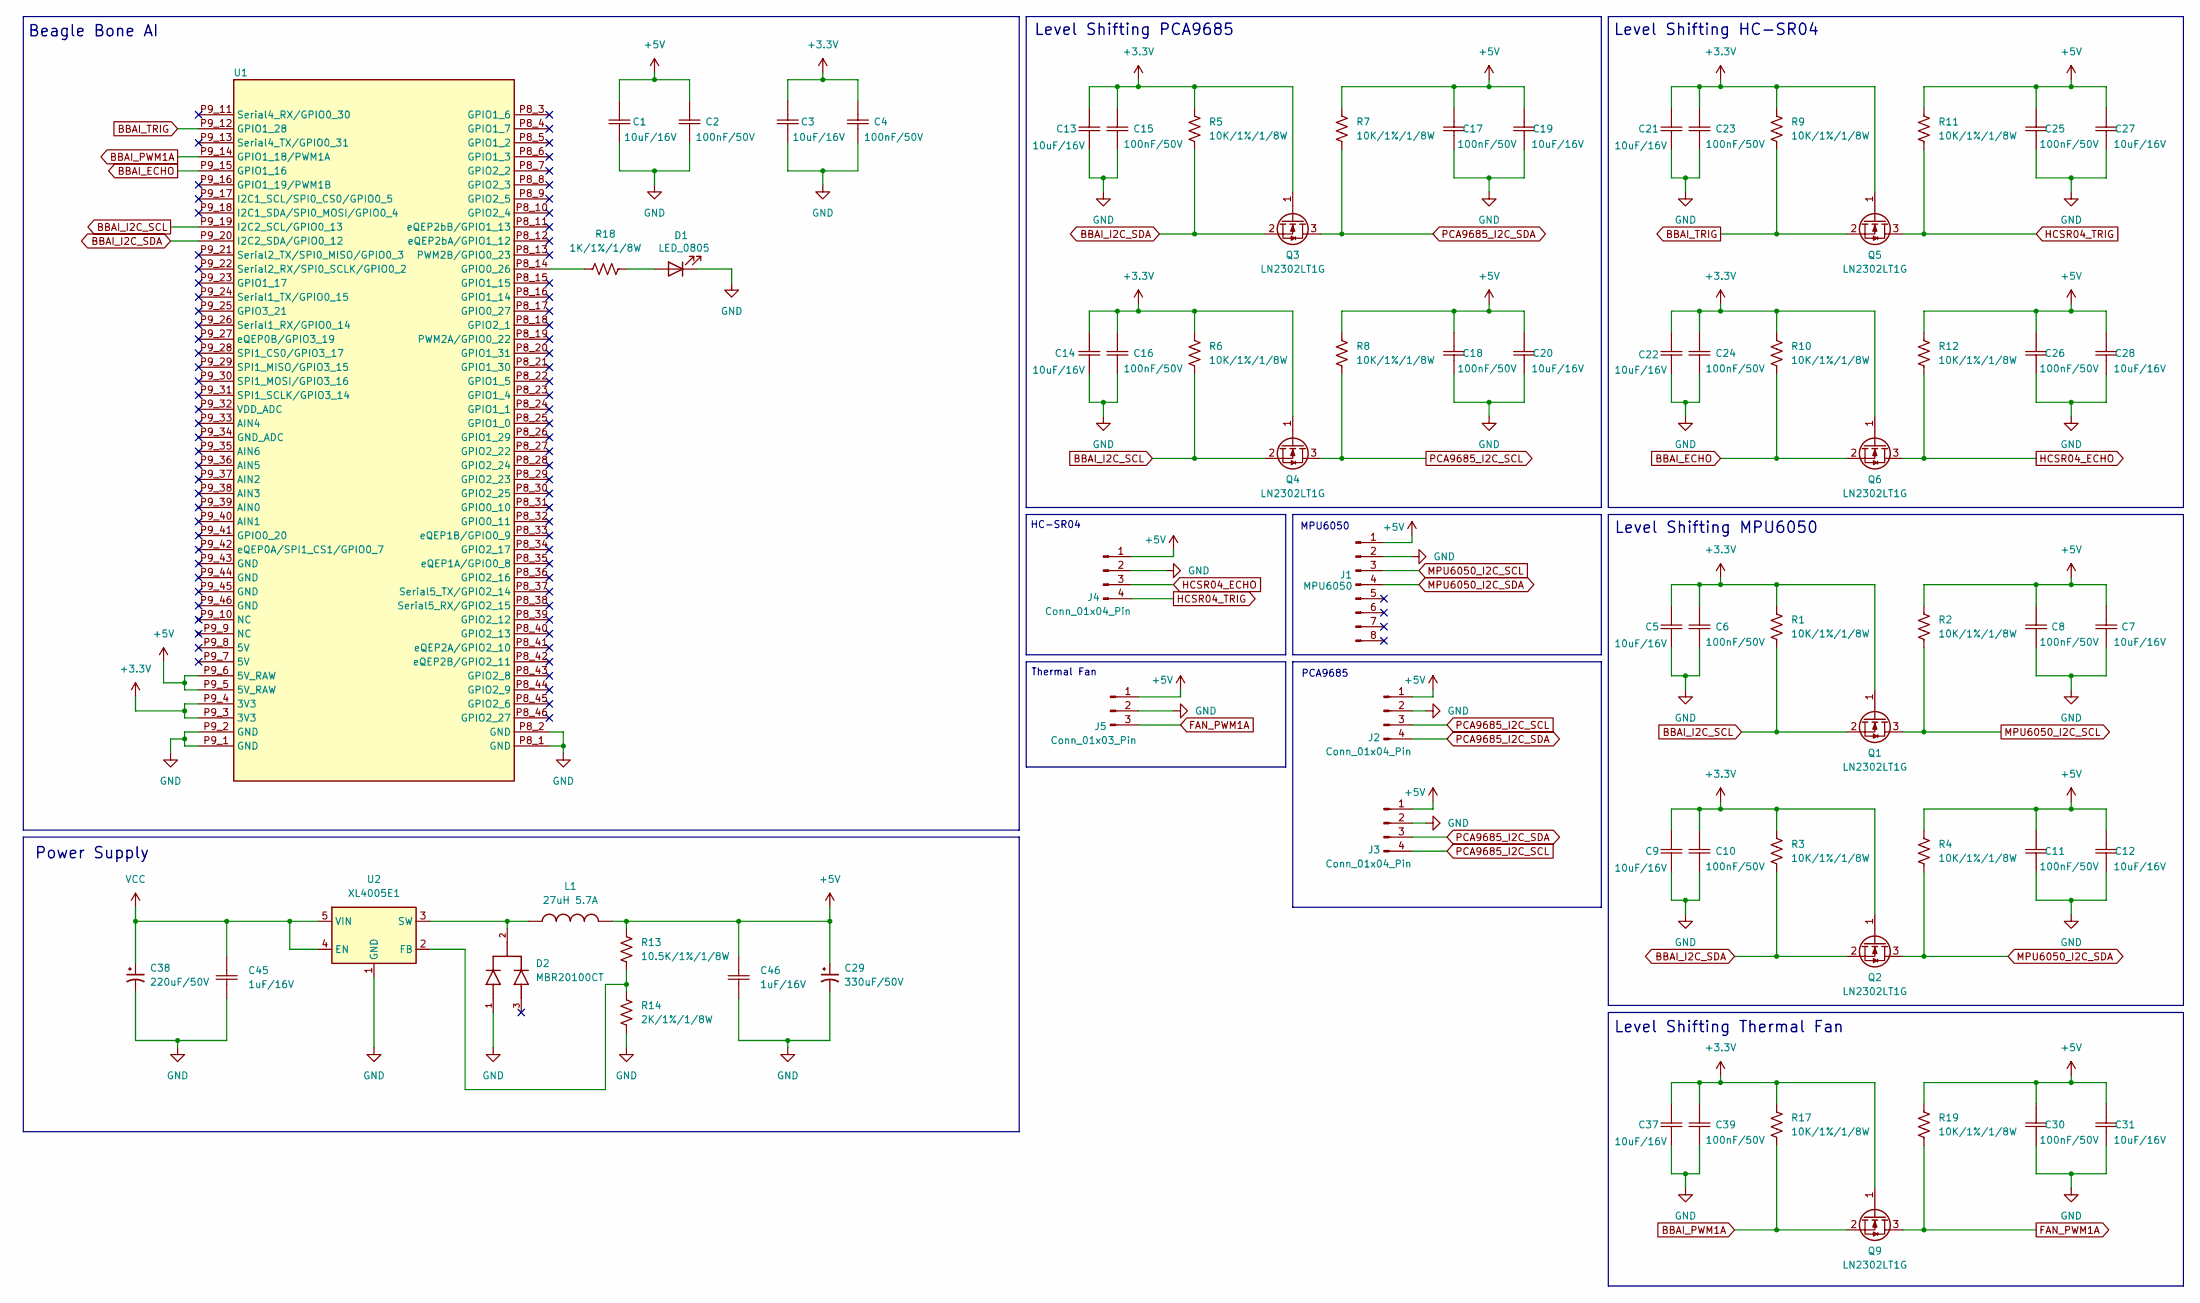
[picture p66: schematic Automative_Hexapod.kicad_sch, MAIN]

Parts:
C1, C3, C5, C7, C9, C12, C13, C14, C19, C20, C21, C22, C27, C28, C31, C37: 10uF/16V; Ceramic_Cap_0805
C2, C4, C6, C8, C10, C11, C15, C16, C17, C18, C23, C24, C25, C26, C30, C39: 100nF/50V; Ceramic_Cap_0805
C29: 330uF/50V; CP_Elec_10x10.5
C38: 220uF/50V; CP_Elec_10x10.5
C45, C46: 1uF/16V; Ceramic_Cap_0805
D1: LED_0805
D2: MBR20100CT; TO-220-3
J1: MPU6050
J2, J3, J4: Conn_01x04_Pin; PinHeader_1x04_P1.00mm_Vertical
J5: Conn_01x03_Pin; PinHeader_1x03_P1.00mm_Vertical
L1: 27uH 5.7A; IND_CDRH127_LDNP-470MC_SUM
Q1, Q2, Q3, Q4, Q5, Q6, Q9: LN2302LT1G; SOT23
R1, R2, R3, R4, R5, R6, R7, R8, R9, R10, R11, R12, R17, R19: 10K/1%/1/8W; Res_0805
R13: 10.5K/1%/1/8W; Res_0805
R14: 2K/1%/1/8W; Res_0805
R18: 1K/1%/1/8W; Res_0805
U1: BeagleBone_AI
U2: XL4005E1; TO-263-5

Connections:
+3.3V: C3.2, C4.2, C5.2, C6.2, C9.2, C10.2, C13.2, C14.2, C15.2, C16.2, C21.2, C22.2, C23.2, C24.2, C37.2, C39.2, Q1.1 (G), Q2.1 (G), Q3.1 (G), Q4.1 (G), Q5.1 (G), Q6.1 (G), Q9.1 (G), R1.2, R3.2, R5.2, R6.2, R9.2, R10.2, R17.2, U1.P9_3 (3V3), U1.P9_4 (3V3)
+5V: C1.2, C2.2, C7.2, C8.2, C11.2, C12.2, C17.2, C18.2, C19.2, C20.2, C25.2, C26.2, C27.2, C28.2, C29.1, C30.2, C31.2, C46.2, J1.1, J2.1, J3.1, J4.1, J5.1, L1.2, R2.2, R4.2, R7.2, R8.2, R11.2, R12.2, R13.2, R19.2, U1.P9_5 (5V_RAW), U1.P9_6 (5V_RAW)
BBAI_ECHO: Q6.2 (S), R10.1, U1.P9_15 (GPIO1_16)
BBAI_I2C_SCL: Q1.2 (S), Q4.2 (S), R1.1, R6.1, U1.P9_19 (I2C2_SCL/GPIO0_13)
BBAI_I2C_SDA: Q2.2 (S), Q3.2 (S), R3.1, R5.1, U1.P9_20 (I2C2_SDA/GPIO0_12)
BBAI_PWM1A: Q9.2 (S), R17.1, U1.P9_14 (GPIO1_18/PWM1A)
BBAI_TRIG: Q5.2 (S), R9.1, U1.P9_12 (GPIO1_28)
FAN_PWM1A: J5.3, Q9.3 (D), R19.1
GND: C1.1, C2.1, C3.1, C4.1, C5.1, C6.1, C7.1, C8.1, C9.1, C10.1, C11.1, C12.1, C13.1, C14.1, C15.1, C16.1, C17.1, C18.1, C19.1, C20.1, C21.1, C22.1, C23.1, C24.1, C25.1, C26.1, C27.1, C28.1, C29.2, C30.1, C31.1, C37.1, C38.2, C39.1, C45.1, C46.1, D1.1 (K), D2.1, J1.2, J2.2, J3.2, J4.2, J5.2, R14.1, U1.P8_1 (GND), U1.P8_2 (GND), U1.P9_1 (GND), U1.P9_2 (GND), U2.1 (GND)
HCSR04_ECHO: J4.3, Q6.3 (D), R12.1
HCSR04_TRIG: J4.4, Q5.3 (D), R11.1
MPU6050_I2C_SCL: J1.3, Q1.3 (D), R2.1
MPU6050_I2C_SDA: J1.4, Q2.3 (D), R4.1
unnamed: D1.2 (A), R18.2
unnamed: R18.1, U1.P8_14 (GPIO0_26)
unnamed: R13.1, R14.2, U2.2 (FB)
unnamed: D2.2, L1.1, U2.3 (SW)
PCA9685_I2C_SCL: J2.3, J3.4, Q4.3 (D), R8.1
PCA9685_I2C_SDA: J2.4, J3.3, Q3.3 (D), R7.1
VCC: C38.1, C45.2, U2.4 (EN), U2.5 (VIN)

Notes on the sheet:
PCA9685
HC-SR04
Thermal Fan
Level Shifting MPU6050
Beagle Bone AI
Level Shifting HC-SR04
Level Shifting Thermal Fan
MPU6050
Level Shifting PCA9685
Power Supply

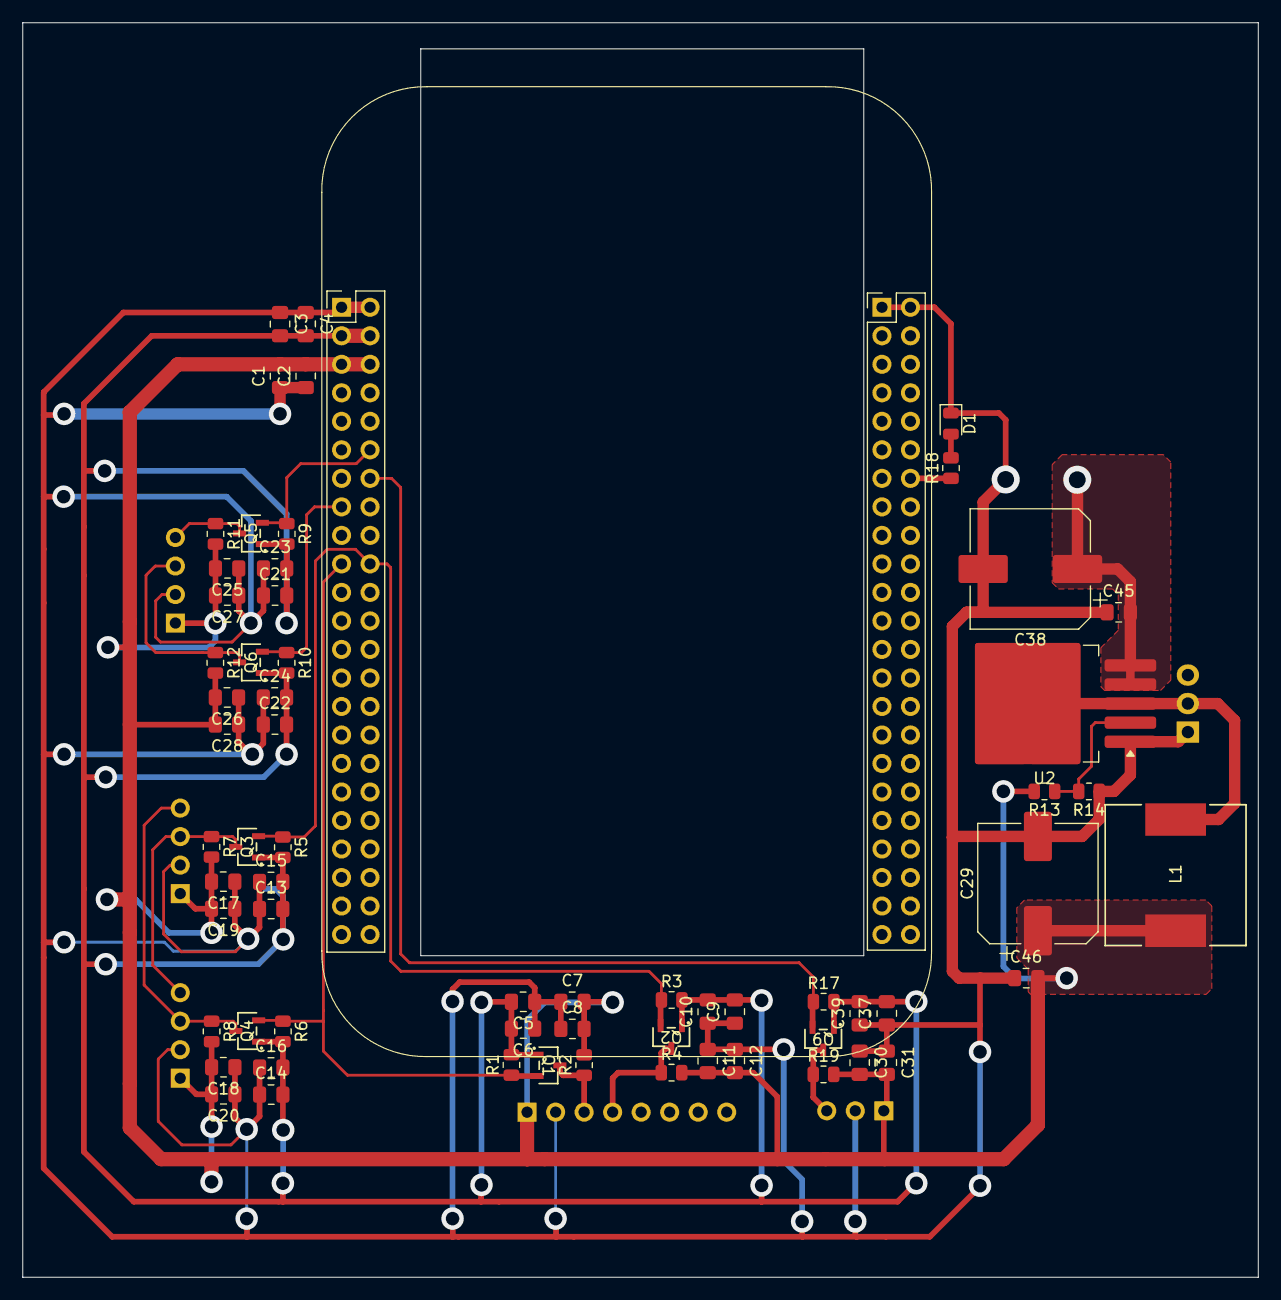
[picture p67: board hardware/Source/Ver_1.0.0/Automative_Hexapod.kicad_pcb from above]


Board: 2 copper layers, 110.1 x 111.8 mm, 70 parts (6 on the bottom side), 20 nets.

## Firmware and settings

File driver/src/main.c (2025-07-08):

/*
 * Hexapod Project - A Reinforcement Learning-based Autonomous Hexapod
 * Copyright (C) 2025  Nguyen Trong Phuc
 *
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
 * You should have received a copy of the GNU General Public License
 * along with this program; if not, write to the Free Software Foundation,
 * Inc., 51 Franklin Street, Fifth Floor, Boston, MA 02110-1301 USA.
 */

/**
 * @file main.c
 * @brief Comprehensive hexapod robot device driver for Linux kernel
 *
 * This driver provides complete control functionality for a hexapod robot with:
 * - 6 legs with 3 servos each (18 total servos via PCA9685)
 * - IMU sensor support (MPU6050 or ADXL345)
 * - Calibration and position control
 * - Character device interface with IOCTL commands
 *
 * The driver integrates all hexapod-specific logic directly into the kernel
 * module, avoiding unnecessary abstraction layers while reusing existing
 * device-specific drivers (PCA9685, MPU6050, ADXL345, servo control).
 *
 * Hardware Interface:
 * - PCA9685: 16-channel PWM controller for servo motors
 * - MPU6050: 6-axis IMU (accelerometer + gyroscope)
 * - ADXL345: 3-axis accelerometer (alternative to MPU6050)
 * - GPIO: Optional status/debug pins
 *
 * @author StrongFood
 * @version 1.0
 * @date 2025
 * @license GPL v2
 */

#include <linux/module.h>
#include <linux/kernel.h>
#include <linux/init.h>
#include <linux/fs.h>
#include <linux/cdev.h>
#include <linux/device.h>
#include <linux/slab.h>
#include <linux/uaccess.h>
#include <linux/i2c.h>
#include <linux/delay.h>
#include <linux/gpio.h>
#include <linux/mutex.h>
#include <linux/string.h>
#include <linux/errno.h>
#include <linux/types.h>
#include <linux/workqueue.h>
#include <linux/timer.h>

/* Include headers for existing device-specific drivers */
#include "pca9685.h"
#include "adxl345.h"
#include "mpu6050.h"
#include "servo.h"

/*============================================================================
 * Module Metadata and Parameters
 *============================================================================*/

MODULE_LICENSE("GPL v2");
MODULE_AUTHOR("StrongFood");
MODULE_DESCRIPTION("A big update for hexapod robot driver with complete functionality");
MODULE_VERSION("1.0");

/**
 * @brief Module debug parameter
 *
 * Enable/disable debug output during module operation
 * Usage: insmod hexapod_driver.ko debug=1
 */
static int debug = 0;
module_param(debug, int, S_IRUGO | S_IWUSR);
MODULE_PARM_DESC(debug, "Enable debug output (0=disabled, 1=enabled)");

/**
 * @brief Default sensor type parameter
 *
 * Set which IMU sensor to use by default
 * 0=MPU6050, 1=ADXL345, 2=Auto-detect
 */
static int default_sensor = 2;
module_param(default_sensor, int, S_IRUGO);
MODULE_PARM_DESC(default_sensor, "Default sensor type (0=MPU6050, 1=ADXL345, 2=auto)");

/**
 * @brief Servo update frequency parameter
 *
 * PWM update frequency for servo control (Hz)
 */
static int servo_freq = SERVO_FREQ_HZ;
module_param(servo_freq, int, S_IRUGO);
MODULE_PARM_DESC(servo_freq, "Servo PWM frequency in Hz (default: 50)");

/*============================================================================
 * Hardware Configuration Constants
 *============================================================================*/

/**
 * @brief Device naming constants
 */
#define DEVICE_NAME "hexapod"
#define CLASS_NAME "hexapod"
#define DRIVER_NAME "hexapod_driver"

/**
 * @brief Hexapod physical configuration
 *
 * These constants define the robot's mechanical structure
 */
#define HEXAPOD_NUM_LEGS 6                                               ///< Number of legs
#define HEXAPOD_SERVOS_PER_LEG 3                                         ///< Servos per leg (hip, knee, ankle)
#define HEXAPOD_TOTAL_SERVOS (HEXAPOD_NUM_LEGS * HEXAPOD_SERVOS_PER_LEG) ///< Total servo count

/**
 * @brief Hexapod mechanical dimensions (millimeters)
 *
 * These values must match the physical robot construction
 */
#define HEXAPOD_COXA_LENGTH 30   ///< Hip segment length (mm)
#define HEXAPOD_FEMUR_LENGTH 85  ///< Upper leg segment length (mm)
#define HEXAPOD_TIBIA_LENGTH 130 ///< Lower leg segment length (mm)

/**
 * @brief Servo angle limits (degrees)
 *
 * Safety limits to prevent mechanical damage
 */
#define HEXAPOD_HIP_MIN_ANGLE -90   ///< Minimum hip angle
#define HEXAPOD_HIP_MAX_ANGLE 90    ///< Maximum hip angle
#define HEXAPOD_KNEE_MIN_ANGLE -90  ///< Minimum knee angle
#define HEXAPOD_KNEE_MAX_ANGLE 90   ///< Maximum knee angle
#define HEXAPOD_ANKLE_MIN_ANGLE -90 ///< Minimum ankle angle
#define HEXAPOD_ANKLE_MAX_ANGLE 90  ///< Maximum ankle angle

/**
 * @brief Servo PWM configuration
 *
 * PWM pulse width mappings for servo control
 */
#define SERVO_PWM_MIN 205    ///< PWM value for -90 degrees (1ms pulse)
#define SERVO_PWM_CENTER 307 ///< PWM value for 0 degrees (1.5ms pulse)
#define SERVO_PWM_MAX 409    ///< PWM value for +90 degrees (2ms pulse)

/**
 * @brief Sensor type enumeration
 *
 * Supported IMU sensor types
 */
typedef enum
{
    HEXAPOD_SENSOR_MPU6050 = 0, ///< MPU6050 6-axis IMU
    HEXAPOD_SENSOR_ADXL345 = 1, ///< ADXL345 3-axis accelerometer
    HEXAPOD_SENSOR_AUTO = 2     ///< Auto-detect available sensor
} hexapod_sensor_type_t;

/*============================================================================
 * IOCTL Interface Definitions
 *============================================================================*/

/**
 * @brief IOCTL magic number for hexapod driver
 *
 * Unique identifier for this driver's IOCTL commands
 */
#define HEXAPOD_IOC_MAGIC 'H'

/**
 * @brief Joint angles structure for leg control
 *
 * Contains angle values for all three joints in a leg
 */
struct hexapod_leg_joint
{
    int16_t hip;   ///< Hip joint angle in degrees (-90 to +90)
    int16_t knee;  ///< Knee joint angle in degrees (-90 to +90)
    int16_t ankle; ///< Ankle joint angle in degrees (-90 to +90)
};

/**
 * @brief Leg command structure for IOCTL interface
 *
 * Used to specify which leg to control and target angles
 */
struct hexapod_leg_cmd
{
    uint8_t leg_num;                ///< Leg number (0-5)
    struct hexapod_leg_joint joint; ///< Target joint angles
};

/**
 * @brief IMU data structure for sensor readings
 *
 * Contains raw accelerometer and gyroscope data
 */
struct hexapod_imu_data
{
    int16_t accel_x; ///< X-axis acceleration (raw sensor value)
    int16_t accel_y; ///< Y-axis acceleration (raw sensor value)
    int16_t accel_z; ///< Z-axis acceleration (raw sensor value)
    int16_t gyro_x;  ///< X-axis angular velocity (raw, 0 for ADXL345)
    int16_t gyro_y;  ///< Y-axis angular velocity (raw, 0 for ADXL345)
    int16_t gyro_z;  ///< Z-axis angular velocity (raw, 0 for ADXL345)
};

/**
 * @brief Calibration data structure for leg adjustment
 *
 * Contains offset values to compensate for mechanical variations
 */
struct hexapod_calibration
{
    uint8_t leg_num;                  ///< Leg number (0-5)
    struct hexapod_leg_joint offsets; ///< Calibration offset angles
};

/**
 * @brief IOCTL command definitions
 *
 * These commands provide the user-space API for robot control
 */
#define HEXAPOD_IOCTL_SET_LEG _IOW(HEXAPOD_IOC_MAGIC, 1, struct hexapod_leg_cmd)       ///< Set leg position
#define HEXAPOD_IOCTL_GET_IMU _IOR(HEXAPOD_IOC_MAGIC, 2, struct hexapod_imu_data)      ///< Get IMU data
#define HEXAPOD_IOCTL_CALIBRATE _IOW(HEXAPOD_IOC_MAGIC, 3, struct hexapod_calibration) ///< Set calibration
#define HEXAPOD_IOCTL_CENTER_ALL _IO(HEXAPOD_IOC_MAGIC, 4)                             ///< Center all legs
#define HEXAPOD_IOCTL_SET_SENSOR_TYPE _IOW(HEXAPOD_IOC_MAGIC, 5, int)                  ///< Set sensor type
#define HEXAPOD_IOCTL_GET_SENSOR_TYPE _IOR(HEXAPOD_IOC_MAGIC, 6, int)                  ///< Get sensor type

/*============================================================================
 * Device State Structure
 *============================================================================*/

/**
 * @brief Main hexapod device state structure
 *
 * Contains all runtime state and configuration for the hexapod device
 */
struct hexapod_device
{
    /* Character device infrastructure */
    struct cdev cdev;      ///< Character device structure
    struct class *class;   ///< Device class pointer
    struct device *device; ///< Device structure pointer
    dev_t devno;           ///< Device number

    /* Hardware state */
    bool pca9685_initialized;          ///< PCA9685 PWM controller status
    bool sensor_initialized;           ///< IMU sensor initialization status
    hexapod_sensor_type_t sensor_type; ///< Current active sensor type

    /* Current robot state */
    struct hexapod_leg_joint leg_positions[HEXAPOD_NUM_LEGS]; ///< Current leg positions
    struct hexapod_leg_joint calibration[HEXAPOD_NUM_LEGS];   ///< Calibration offsets
    struct hexapod_imu_data imu_data;                         ///< Last IMU reading

    /* Synchronization */
    struct mutex device_lock; ///< Device access mutex

    /* Operational statistics */
    unsigned long cmd_count;   ///< Total commands processed
    unsigned long error_count; ///< Total errors encountered
    ktime_t last_update;       ///< Time of last state update
};

/*============================================================================
 * Global Variables
 *============================================================================*/

/**
 * @brief Global device state pointer
 *
 * Single instance of the hexapod device
 */
static struct hexapod_device *hexapod_dev = NULL;

/**
 * @brief Device number for character device
 */
static dev_t hexapod_major;

/*============================================================================
 * Debug and Logging Macros
 *============================================================================*/

/**
 * @brief Debug print macro
 *
 * Prints debug messages when debug parameter is enabled
 */
#define hexapod_dbg(fmt, ...)                             \
    do                                                    \
    {                                                     \
        if (debug)                                        \
            pr_info(DRIVER_NAME ": " fmt, ##__VA_ARGS__); \
    } while (0)

/**
 * @brief Error print macro
 *
 * Always prints error messages with consistent formatting
 */
#define hexapod_err(fmt, ...) \
    pr_err(DRIVER_NAME ": " fmt, ##__VA_ARGS__)

/**
 * @brief Warning print macro
 *
 * Prints warning messages with consistent formatting
 */
#define hexapod_warn(fmt, ...) \
    pr_warn(DRIVER_NAME ": " fmt, ##__VA_ARGS__)

/**
 * @brief Info print macro
 *
 * Prints informational messages with consistent formatting
 */
#define hexapod_info(fmt, ...) \
    pr_info(DRIVER_NAME ": " fmt, ##__VA_ARGS__)

/*============================================================================
 * Utility Functions
 *============================================================================*/

/**
 * @brief Convert servo angle to PWM pulse width
 *
 * Maps an angle in degrees to the appropriate PWM pulse width value
 * for servo control via PCA9685
 *
 * @param angle Angle in degrees (-90 to +90)
 * @return PWM pulse width value (205-409)
 */
static uint16_t hexapod_angle_to_pwm(int16_t angle)
{
    int32_t pwm_value;

    /* Clamp angle to valid range for safety */
    if (angle < -90)
        angle = -90;
    if (angle > 90)
        angle = 90;

    /* Linear mapping: [-90, +90] -> [205, 409]
     * Formula: PWM = ((angle + 90) * (409 - 205) / 180) + 205
     */
    pwm_value = ((angle + 90) * (SERVO_PWM_MAX - SERVO_PWM_MIN) / 180) + SERVO_PWM_MIN;

    hexapod_dbg("Angle %d mapped to PWM %d", angle, pwm_value);

    return (uint16_t)pwm_value;
}

/**
 * @brief Validate leg number
 *
 * Checks if the provided leg number is within valid range
 *
 * @param leg_num Leg number to validate
 * @return true if valid, false otherwise
 */
static bool hexapod_is_valid_leg(uint8_t leg_num)
{
    return (leg_num < HEXAPOD_NUM_LEGS);
}

/**
 * @brief Validate joint angles
 *
 * Checks if all joint angles are within safe operating ranges
 *
 * @param joint Pointer to joint angles structure
 * @return true if all angles are valid, false otherwise
 */
static bool hexapod_validate_joint_angles(const struct hexapod_leg_joint *joint)
{
    if (!joint)
    {
        hexapod_err("NULL joint pointer");
        return false;
    }

    /* Check hip angle range */
    if (joint->hip < HEXAPOD_HIP_MIN_ANGLE || joint->hip > HEXAPOD_HIP_MAX_ANGLE)
    {
        hexapod_err("Hip angle %d out of range [%d, %d]",
                    joint->hip, HEXAPOD_HIP_MIN_ANGLE, HEXAPOD_HIP_MAX_ANGLE);
        return false;
    }

    /* Check knee angle range */
    if (joint->knee < HEXAPOD_KNEE_MIN_ANGLE || joint->knee > HEXAPOD_KNEE_MAX_ANGLE)
    {
        hexapod_err("Knee angle %d out of range [%d, %d]",
                    joint->knee, HEXAPOD_KNEE_MIN_ANGLE, HEXAPOD_KNEE_MAX_ANGLE);
        return false;
    }

    /* Check ankle angle range */
    if (joint->ankle < HEXAPOD_ANKLE_MIN_ANGLE || joint->ankle > HEXAPOD_ANKLE_MAX_ANGLE)
    {
        hexapod_err("Ankle angle %d out of range [%d, %d]",
                    joint->ankle, HEXAPOD_ANKLE_MIN_ANGLE, HEXAPOD_ANKLE_MAX_ANGLE);
        return false;
    }

    return true;
}

/*============================================================================
 * Hardware Initialization Functions
 *============================================================================*/

/**
 * @brief Initialize PCA9685 PWM controller
 *
 * Sets up the PCA9685 device for servo control with appropriate frequency
 * and configuration. Uses the existing pca9685.h API functions.
 *
 * @return 0 on success, negative error code on failure
 */
static int hexapod_init_pca9685(void)
{
    int ret;

    hexapod_dbg("Initializing PCA9685 PWM controller");

    /* Initialize PCA9685 using existing driver API */
    ret = pca9685_init();
    if (ret < 0)
    {
        hexapod_err("Failed to initialize PCA9685: %d", ret);
        return ret;
    }

    /* Set PWM frequency for servo control */
    ret = pca9685_set_pwm_freq(servo_freq);
    if (ret < 0)
    {
        hexapod_err("Failed to set PCA9685 frequency to %d Hz: %d", servo_freq, ret);
        return ret;
    }

    hexapod_info("PCA9685 initialized with %d Hz frequency", servo_freq);
    return 0;
}

/**
 * @brief Initialize IMU sensor
 *
 * Initializes the appropriate IMU sensor based on configuration.
 * Supports MPU6050, ADXL345, or auto-detection.
 *
 * @param dev Hexapod device structure
 * @return 0 on success, negative error code on failure
 */
static int hexapod_init_sensor(struct hexapod_device *dev)
{
    int ret = -EINVAL;

    if (!dev)
    {
        hexapod_err("NULL device pointer");
        return -EINVAL;
    }

    /* Skip if already initialized */
    if (dev->sensor_initialized)
    {
        hexapod_dbg("Sensor already initialized");
        return 0;
    }

    hexapod_dbg("Initializing sensor type %d", dev->sensor_type);

    switch (dev->sensor_type)
    {
    case HEXAPOD_SENSOR_MPU6050:
        hexapod_info("Initializing MPU6050 sensor");
        ret = mpu6050_init();
        if (ret == 0)
        {
            hexapod_info("MPU6050 sensor initialized successfully");
        }
        break;

    case HEXAPOD_SENSOR_ADXL345:
        hexapod_info("Initializing ADXL345 sensor");
        ret = adxl345_init(ADXL345_I2C_BUS);
        if (ret == 0)
        {
            hexapod_info("ADXL345 sensor initialized successfully");
        }
        break;

    case HEXAPOD_SENSOR_AUTO:
        hexapod_info("Auto-detecting IMU sensor");
        /* Try MPU6050 first */
        ret = mpu6050_init();
        if (ret == 0)
        {
            dev->sensor_type = HEXAPOD_SENSOR_MPU6050;
            hexapod_info("Auto-detected MPU6050 sensor");
        }
        else
        {
            /* Fall back to ADXL345 */
            ret = adxl345_init(ADXL345_I2C_BUS);
            if (ret == 0)
            {
                dev->sensor_type = HEXAPOD_SENSOR_ADXL345;
                hexapod_info("Auto-detected ADXL345 sensor");
            }
            else
            {
                hexapod_err("No IMU sensor detected during auto-detection");
                return -ENODEV;
            }
        }
        break;

    default:
        hexapod_err("Invalid sensor type: %d", dev->sensor_type);
        return -EINVAL;
    }

    if (ret < 0)
    {
        hexapod_err("Failed to initialize sensor: %d", ret);
        return ret;
    }

    dev->sensor_initialized = true;
    return 0;
}

/*============================================================================
 * Servo Control Functions
 *============================================================================*/

/**
 * @brief Set position for a single servo
 *
 * Controls a specific servo by converting angle to PWM and using PCA9685
 *
 * @param servo_num Servo number (0-17)
 * @param angle Target angle in degrees (-90 to +90)
 * @return 0 on success, negative error code on failure
 */
static int hexapod_set_servo_position(uint8_t servo_num, int16_t angle)
{
    uint16_t pwm_value;
    int ret;

    /* Validate servo number */
    if (servo_num >= HEXAPOD_TOTAL_SERVOS)
    {
        hexapod_err("Invalid servo number: %d (max: %d)", servo_num, HEXAPOD_TOTAL_SERVOS - 1);
        return -EINVAL;
    }

    /* Convert angle to PWM value */
    pwm_value = hexapod_angle_to_pwm(angle);

    /* Set servo position using PCA9685 driver */
    ret = pca9685_set_pwm(servo_num, 0, pwm_value);
    if (ret < 0)
    {
        hexapod_err("Failed to set servo %d to angle %d: %d", servo_num, angle, ret);
        return ret;
    }

    hexapod_dbg("Servo %d set to angle %d (PWM %d)", servo_num, angle, pwm_value);
    return 0;
}

/**
 * @brief Set position for all joints in a leg
 *
 * Controls all three servos in a specific leg, applying calibration offsets
 *
 * @param dev Hexapod device structure
 * @param cmd Leg command with target angles
 * @return 0 on success, negative error code on failure
 */
static int hexapod_set_leg_position(struct hexapod_device *dev,
                                    const struct hexapod_leg_cmd *cmd)
{
    uint8_t base_servo;
    int16_t hip_angle, knee_angle, ankle_angle;
    int ret;

    if (!dev || !cmd)
    {
        hexapod_err("NULL pointer in set_leg_position");
        return -EINVAL;
    }

    /* Validate leg number */
    if (!hexapod_is_valid_leg(cmd->leg_num))
    {
        hexapod_err("Invalid leg number: %d", cmd->leg_num);
        return -EINVAL;
    }

    /* Validate joint angles */
    if (!hexapod_validate_joint_angles(&cmd->joint))
    {
        return -EINVAL;
    }

    /* Calculate base servo number for this leg */
    base_servo = cmd->leg_num * HEXAPOD_SERVOS_PER_LEG;

    /* Apply calibration offsets */
    hip_angle = cmd->joint.hip + dev->calibration[cmd->leg_num].hip;
    knee_angle = cmd->joint.knee + dev->calibration[cmd->leg_num].knee;
    ankle_angle = cmd->joint.ankle + dev->calibration[cmd->leg_num].ankle;

    hexapod_dbg("Setting leg %d: hip=%d, knee=%d, ankle=%d (with calibration)",
                cmd->leg_num, hip_angle, knee_angle, ankle_angle);

    /* Set servo positions for each joint */
    ret = hexapod_set_servo_position(base_servo, hip_angle);
    if (ret < 0)
    {
        hexapod_err("Failed to set hip servo for leg %d", cmd->leg_num);
        return ret;
    }

    ret = hexapod_set_servo_position(base_servo + 1, knee_angle);
    if (ret < 0)
    {
        hexapod_err("Failed to set knee servo for leg %d", cmd->leg_num);
        return ret;
    }

    ret = hexapod_set_servo_position(base_servo + 2, ankle_angle);
    if (ret < 0)
    {
        hexapod_err("Failed to set ankle servo for leg %d", cmd->leg_num);
        return ret;
    }

    /* Store current position (without calibration for user reference) */
    dev->leg_positions[cmd->leg_num] = cmd->joint;

    hexapod_dbg("Leg %d positioned successfully", cmd->leg_num);
    return 0;
}

/**
 * @brief Center all legs to neutral position
 *
 * Sets all leg joints to 0 degrees (center position)
 *
 * @param dev Hexapod device structure
 * @return 0 on success, negative error code on failure
 */
static int hexapod_center_all_legs(struct hexapod_device *dev)
{
    struct hexapod_leg_cmd cmd;
    int ret;
    int i;

    if (!dev)
    {
        hexapod_err("NULL device pointer");
        return -EINVAL;
    }

    hexapod_info("Centering all legs");

    /* Set all legs to center position */
    cmd.joint.hip = 0;
    cmd.joint.knee = 0;
    cmd.joint.ankle = 0;

    for (i = 0; i < HEXAPOD_NUM_LEGS; i++)
    {
        cmd.leg_num = i;

        ret = hexapod_set_leg_position(dev, &cmd);
        if (ret < 0)
        {
            hexapod_err("Failed to center leg %d: %d", i, ret);
            return ret;
        }

        /* Small delay between leg movements for smoother operation */
        mdelay(50);
    }

    hexapod_info("All legs centered successfully");
    return 0;
}

/*============================================================================
 * IMU Sensor Functions
 *============================================================================*/
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

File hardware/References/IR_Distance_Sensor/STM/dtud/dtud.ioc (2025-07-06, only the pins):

Mcu.UserName=STM32F103C8Tx
PA0-WKUP.Signal=ADCx_IN0
PA13.Signal=SYS_JTMS-SWDIO
PA14.Signal=SYS_JTCK-SWCLK
PB7.Signal=GPIO_Output
PB8.Signal=GPIO_Output
PB9.Signal=GPIO_Output
PC13-TAMPER-RTC.Signal=GPIO_Output
PD0-OSC_IN.Signal=RCC_OSC_IN
PD1-OSC_OUT.Signal=RCC_OSC_OUT

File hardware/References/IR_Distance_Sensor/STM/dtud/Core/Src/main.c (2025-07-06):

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
/* Includes ------------------------------------------------------------------*/
#include "main.h"

ADC_HandleTypeDef hadc1;

/* USER CODE BEGIN PV */
uint16_t Sens, Sens1[256];;
float voltage_sum, voltage;
/* USER CODE END PV */

void SystemClock_Config(void);
static void MX_GPIO_Init(void);
static void MX_ADC1_Init(void);
/* USER CODE BEGIN 0 */
void HAL_ADC_ConvCpltCallback(ADC_HandleTypeDef* hadc)
{
  /* Prevent unused argument(s) compilation warning */
  UNUSED(hadc);
  if (hadc->Instance == ADC1)
  {
	  Sens = HAL_ADC_GetValue(&hadc1);
  }
}

/* USER CODE END 0 */

/**
  * @brief  The application entry point.
  * @retval int
  */
int main(void)
{
  /* MCU Configuration--------------------------------------------------------*/

  /* Reset of all peripherals, Initializes the Flash interface and the Systick. */
  HAL_Init();

  /* Configure the system clock */
  SystemClock_Config();

  /* Initialize all configured peripherals */
  MX_GPIO_Init();
  MX_ADC1_Init();
  /* USER CODE BEGIN 2 */

  uint8_t i=0;
  char ok=0;
  HAL_ADC_Start_IT(&hadc1);
  /* USER CODE END 2 */

  /* Infinite loop */
  /* USER CODE BEGIN WHILE */
  while (1)
  {
    /* USER CODE END WHILE */

    /* USER CODE BEGIN 3 */
//	  HAL_GPIO_TogglePin(GPIOC, GPIO_PIN_13);
	  HAL_GPIO_WritePin(GPIOC, GPIO_PIN_13, ok);
	  Sens1[i++]=Sens;
	  voltage_sum=0;
	  for (int var = 0; var < 256; ++var) {
		  voltage_sum+=Sens1[var]*3.3/4096;
	  }
	  voltage=0.9987*(voltage_sum/256)+0.0504;
	  ok=1;
	  if(voltage>=0.409)//>=0.409V
	  {
		  if (voltage>=0.487)//>=0.487V
		  {
			  if (voltage>=0.493)//>=0.493V
			  {
				  if (voltage>=0.78125)//>=0.78125V
				  {
					  if (voltage>=0.79775)//>=0.79775V
					  {
						  if (voltage>=1.236)//>=1.236V
						  {
							  if (voltage>=1.286)//>=1.286V
							  {
									if (voltage>=2.315) //>=2.315
										//state!
										ok=0;
									else //stateIV
									{
										  HAL_GPIO_WritePin(GPIOB, GPIO_PIN_7, 1);
										  HAL_GPIO_WritePin(GPIOB, GPIO_PIN_8, 1);
										  HAL_GPIO_WritePin(GPIOB, GPIO_PIN_9, 0);
									}
							  }
							  //state0
						  }
						  else //stateIII
						  {
							  HAL_GPIO_WritePin(GPIOB, GPIO_PIN_7, 0);
							  HAL_GPIO_WritePin(GPIOB, GPIO_PIN_8, 1);
							  HAL_GPIO_WritePin(GPIOB, GPIO_PIN_9, 0);

						  }
					  }
					  //state0
				  }
				  else //stateII
				  {
					  HAL_GPIO_WritePin(GPIOB, GPIO_PIN_7, 0);
					  HAL_GPIO_WritePin(GPIOB, GPIO_PIN_8, 0);
					  HAL_GPIO_WritePin(GPIOB, GPIO_PIN_9, 1);
				  }
			  }
			  //state0
		  }
		  else //stateI
		  {
				HAL_GPIO_WritePin(GPIOB, GPIO_PIN_7, 0);
				HAL_GPIO_WritePin(GPIOB, GPIO_PIN_8, 0);
				HAL_GPIO_WritePin(GPIOB, GPIO_PIN_9, 0);

		  }
	  }
	  else
		  //state!
		  ok=0;
  }
  /* USER CODE END 3 */
}

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


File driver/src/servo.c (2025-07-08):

/**
 * @file servo.c
 * @brief Kernel-space driver for controlling servos
 */

#include <linux/module.h>
#include <linux/errno.h>
#include <linux/mutex.h>
#include <linux/sched.h>
#include "servo.h"
#include "pca9685.h"

/* Module parameters */
static int servo_debug = 0;
module_param(servo_debug, int, 0644);
MODULE_PARM_DESC(servo_debug, "Enable debug output (0=disabled, 1=enabled)");

/* Servo driver state */
struct servo_driver
{
    int initialized;                                       /* Initialization status flag */
    struct mutex lock;                                     /* Thread synchronization lock */
    s16 offsets[SERVO_NUM_LEGS][SERVO_NUM_JOINTS_PER_LEG]; /* Calibration offsets */
};

/* Global driver state */
static struct servo_driver servo_drv = {
    .initialized = 0,
};

/* Servo mapping - which channel for each servo */
static const u8 servo_map[SERVO_NUM_LEGS][SERVO_NUM_JOINTS_PER_LEG] = {
    {0, 1, 2},  /* Leg 0 - First PCA9685 */
    {4, 5, 6},  /* Leg 1 - First PCA9685 */
    {8, 9, 10}, /* Leg 2 - First PCA9685 */
    {0, 1, 2},  /* Leg 3 - Second PCA9685 */
    {4, 5, 6},  /* Leg 4 - Second PCA9685 */
    {8, 9, 10}  /* Leg 5 - Second PCA9685 */
};

/* Which PCA9685 controller to use for each leg (0=primary, 1=secondary) */
static const u8 leg_controller[SERVO_NUM_LEGS] = {
    0, 0, 0, /* First 3 legs use first controller */
    1, 1, 1  /* Last 3 legs use second controller */
};

/**
 * Convert angle in degrees to pulse width in microseconds
 *
 * @param angle Angle in degrees (-90 to +90)
 * @return Pulse width in microseconds
 */
static inline u16 angle_to_pulse(s16 angle)
{
    /* Ensure angle is within valid range */
    if (angle < SERVO_MIN_ANGLE)
        angle = SERVO_MIN_ANGLE;
    else if (angle > SERVO_MAX_ANGLE)
        angle = SERVO_MAX_ANGLE;

    /* Convert angle to pulse width: 1500µs ± (angle * 500µs / 90°) */
    return SERVO_CENTER_US + ((angle * SERVO_RANGE_US) / SERVO_MAX_ANGLE);
}

/**
 * Validate channel parameters
 *
 * @param leg Leg number
 * @param joint Joint number
 * @return 0 if valid, -EINVAL if invalid
 */
static inline int validate_channel(u8 leg, u8 joint)
{
    if (leg >= SERVO_NUM_LEGS || joint >= SERVO_NUM_JOINTS_PER_LEG)
        return -EINVAL;
    return 0;
}

/**
 * Initialize servo control system
 *
 * @return 0 on success, negative error code on failure
 */
int servo_init(void)
{
    int ret;

    pr_info("Servo: Initializing servo subsystem\n");

    /* Check if already initialized */
    if (servo_drv.initialized)
    {
        pr_warn("Servo: Already initialized\n");
        return 0;
    }

    /* Initialize lock */
    mutex_init(&servo_drv.lock);

    /* Clear all calibration offsets */
    memset(servo_drv.offsets, 0, sizeof(servo_drv.offsets));

    /* Set PWM frequency for servos (50Hz standard) */
    ret = pca9685_set_pwm_freq(SERVO_FREQ_HZ);
    if (ret < 0)
    {
        pr_err("Servo: Failed to set PWM frequency: %d\n", ret);
        return ret;
    }

    /* Mark as initialized BEFORE centering servos */
    servo_drv.initialized = 1;

    /* Center all servos for safe starting position */
    ret = servo_center_all();
    if (ret < 0)
    {
        pr_err("Servo: Failed to center servos: %d\n", ret);
        servo_drv.initialized = 0; /* Reset flag on failure */
        return ret;
    }

    pr_info("Servo: Subsystem initialized successfully\n");
    return 0;
}

/**
 * Clean up servo control system
 */
void servo_cleanup(void)
{
    pr_info("Servo: Cleaning up subsystem\n");

    /* Only proceed if initialized */
    if (!servo_drv.initialized)
        return;

    /* Center all servos before shutting down for safety */
    if (servo_center_all() < 0)
        pr_warn("Servo: Failed to center servos during cleanup\n");

    servo_drv.initialized = 0;
    pr_info("Servo: Subsystem cleaned up\n");
}

/**
 * Set servo angle for a specific leg and joint
 *
 * @param leg Leg number (0-5)
 * @param joint Joint number (0=hip, 1=knee, 2=ankle)
 * @param angle Angle in degrees (-90 to +90)
 * @return 0 on success, negative error code on failure
 */
int servo_set_angle(u8 leg, u8 joint, s16 angle)
{
    int ret;
    u8 channel;
    u16 pulse_width;
    static int first_command = 1;

    /* Parameter validation */
    ret = validate_channel(leg, joint);
    if (ret < 0)
        return ret;

    if (!servo_drv.initialized)
    {
        pr_err("Servo: Subsystem not initialized\n");
        return -ENODEV;
    }

    /* Lock for thread safety */
    mutex_lock(&servo_drv.lock);

    /* On first servo command, ensure PWM outputs are enabled */
    if (first_command)
    {
        ret = pca9685_enable_outputs();
        if (ret < 0)
        {
            pr_err("Servo: Failed to enable PWM outputs: %d\n", ret);
            mutex_unlock(&servo_drv.lock);
            return ret;
        }
        first_command = 0;
    }

    /* Get the appropriate channel number */
    channel = servo_map[leg][joint];

    /* Apply controller offset for second PCA9685 */
    if (leg_controller[leg] == 1)
    {
        channel += PCA9685_CHANNELS_PER_DEVICE;
    }

    /* Apply calibration offset */
    angle += servo_drv.offsets[leg][joint];

    /* Convert angle to pulse width */
    pulse_width = angle_to_pulse(angle);

    if (servo_debug)
        pr_info("Servo: Setting leg %u, joint %u (channel %u) to %d° (pulse %uµs)\n",
                leg, joint, channel, angle, pulse_width);

    /* Set the pulse width on PCA9685 */
    ret = pca9685_set_pwm_us(channel, pulse_width);
    if (ret < 0)
    {
        pr_err("Servo: Failed to set PWM for leg %u, joint %u (channel %u): %d\n",
               leg, joint, channel, ret);
    }

    mutex_unlock(&servo_drv.lock);
    return ret;
}

/**
 * Set calibration offsets for a specific leg
 *
 * @param leg Leg number (0-5)
 * @param hip_offset Hip joint offset in degrees
 * @param knee_offset Knee joint offset in degrees
 * @param ankle_offset Ankle joint offset in degrees
 * @return 0 on success, negative error code on failure
 */
int servo_set_calibration(u8 leg, s16 hip_offset, s16 knee_offset, s16 ankle_offset)
{
    if (leg >= SERVO_NUM_LEGS)
        return -EINVAL;

    if (!servo_drv.initialized)
    {
        pr_err("Servo: Subsystem not initialized\n");
        return -ENODEV;
    }

    mutex_lock(&servo_drv.lock);

    /* Store offsets for future use */
    servo_drv.offsets[leg][0] = hip_offset;
    servo_drv.offsets[leg][1] = knee_offset;
    servo_drv.offsets[leg][2] = ankle_offset;

    if (servo_debug)
    {
        pr_info("Servo: Calibration set for leg %u: hip=%d°, knee=%d°, ankle=%d°\n",
                leg, hip_offset, knee_offset, ankle_offset);
    }

    mutex_unlock(&servo_drv.lock);
    return 0;
}
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

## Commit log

2025-02-19 Modify our kernel driver for optimizations
2025-02-20 Update .gitignore and hexapod kernel driver
2025-02-21 Rewrite and update kernel drivers
2025-02-26 Update the inverse kinematics algorithm
2025-02-26 Finish the inverse kinematics algorithms testing
2025-03-20 Patch the kernel drivers related to the second PCA9685
2025-03-21 Modify and repair the some kernel drivers
2025-03-24 Optimize the kernel drivers and user space programs by making them better
2025-03-28 Patching the MPU6050 wake-up error after re-running the testing program for this peripheral
    [mpu6050.c, pca9685.c, pca9685.h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]
2025-03-29 Replace C with Cpp syntax
    [controller.cpp, pca9685.c, servo.cpp]
2025-04-11 Hexapod Monitoring Application by Qt Framework
2025-04-11 The overview of architecture, state and flowchart of this project
2025-04-12 Fix the syntax error by replacing device to artifact
2025-04-21 Modifying and fixing the td3learn algorithm
    [default.yaml]
2025-04-26 Create MPU6050 and PCA9685 device tree for the better cases
2025-05-20 Update entrypoint.sh script to match with the current Dockerfile environment
2025-06-07 Add the HC-SR04 sensor's documents
2025-06-07 Add a new sensor to hexapod
2025-06-14 Modify and add more changes to support a new integrated sensor
2025-06-15 Add the BeagleBone AI schematic
2025-06-15 Update the ultrasonic API functions's implementations using sysfs interface instead of libgpiod usage
2025-06-15 Update the ultrasonic testing program using new its API functions
2025-06-15 Update READ.md to add new ultrasonic implementations
2025-06-25 Replace the HC-SR04 sensor with new one using the ADC mechanism
    [controller.cpp, ultrasonic.cpp]
2025-06-25 Replace the HC-SR04 sensor documents with new one
2025-06-26 Create a common header and then include this to the testing programs with new API functions replacement
    [common.hpp, main.cpp, servo.cpp]
2025-06-28 Update Hardware: Schematic V1.0.0
    [Automative_Hexapod.kicad_pcb, Automative_Hexapod.kicad_sch]
2025-06-28 Schematic V1.0.0
2025-06-28 upload pcb
    [Automative_Hexapod.kicad_pcb]
2025-06-28 Change the leg's servo order
2025-06-28 Update PCB: TestBoard_V1.0.0
    [Automative_Hexapod.kicad_pcb, Automative_Hexapod.kicad_sch]
2025-06-29 update folder hardware
    [Automative_Hexapod.kicad_pcb, Automative_Hexapod.kicad_sch, BBAI.kicad_sch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]
2025-06-29 Pull request
    [Automative_Hexapod.kicad_pcb, Automative_Hexapod.kicad_sch]
2025-06-29 upload test ir distance
    [Automative_Hexapod.kicad_sch, Test_IR_Distance.kicad_pcb, Test_IR_Distance.kicad_sch]
2025-06-29 Update Reference Project for IR Sensor
    [Distance.dwg, Distance.stl, Distance_table.stl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]
2025-07-01 Update Library for Ver 2
    [Automative_Hexapod.kicad_pcb, Automative_Hexapod.kicad_sch, BBAI.kicad_sch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]
2025-07-03 update pcb v1.1.0
    [Automative_Hexapod.kicad_pcb, Automative_Hexapod.kicad_sch, BBAI.kicad_sch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]
2025-07-04 Create and implement the pair of ultrasonic and its testing program
2025-07-06 update pcb and schematic
    [Automative_Hexapod.kicad_pcb, BBAI.kicad_sch, ConnectorServo.kicad_sch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]
2025-07-06 update pcb
    [Automative_Hexapod.kicad_pcb]
2025-07-06 Add the ultrasonic documents for HC-SR04 sensor model
2025-07-06 Modify the device ID to match with the i2c address
2025-07-06 Extend the IMU sensor by adding new one, ADXL345
2025-07-06 Extend the related files to support the switch mechanism between mpu6050 and adxl345 devices
2025-07-08 Update PCB Ver_1.1.0
    [Automative_Hexapod.kicad_pcb, IMU.kicad_sch, PowerSupply.kicad_sch]
2025-07-12 Rename the kernel driver dependencies from .ko to .o extension files
2025-07-13 Generate Gerber V1.1.0
    [Automative_Hexapod-B_Cu.gbr, Automative_Hexapod-B_Mask.gbr, Automative_Hexapod-B_Paste.gbr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]

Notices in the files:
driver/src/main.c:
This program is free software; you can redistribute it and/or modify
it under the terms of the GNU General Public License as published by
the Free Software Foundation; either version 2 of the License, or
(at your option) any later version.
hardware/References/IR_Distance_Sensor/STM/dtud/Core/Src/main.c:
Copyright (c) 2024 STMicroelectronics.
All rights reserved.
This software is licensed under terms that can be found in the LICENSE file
